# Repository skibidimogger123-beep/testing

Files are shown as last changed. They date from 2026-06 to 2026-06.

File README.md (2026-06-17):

# TDKwarriors — WRO Future Engineers 2026

Welcome to the official repository of **Team TDKwarriors** for **WRO Future Engineers 2026**.

This repository contains the complete engineering documentation, software, CAD files, wiring diagrams, and development history of our autonomous robot vehicle.

---

# Team

## Members

* **Mussabek Nurtas**
* **Mukhtar Gulsim**

## Team Photo

Team photo

---

# Project Overview

Our robot is a compact autonomous vehicle designed for the **WRO Future Engineers 2026** competition.

The robot is capable of completing both competition tasks:

### Open Challenge

* Complete 3 autonomous laps
* Maintain stable lane following
* Navigate using distance sensors

### Obstacle Challenge

* Detect red and green pillars
* Choose the correct passing side
* Avoid obstacles
* Recover to the driving line
* Complete 3 laps
* Perform autonomous parking

---

# Robot Photos

## Front View

Vehicle front

## Back View

Vehicle back

## Left View

Vehicle left

## Right View

Vehicle right

## Top View

Vehicle top

## Bottom View

Vehicle bottom

---

# Mobility and Mechanical Design

## Chassis and Drive System

The robot uses a LEGO Technic based chassis with rear-wheel drive and front-wheel steering.

For steering, we selected the **SPIKE Medium Motor** because it provides significantly higher positioning accuracy compared to the Powered Up motor.

### Engineering Trade-Off

| Option | Advantage | Disadvantage |
| --- | --- | --- |
| SPIKE Medium Motor | High steering precision | Lower torque |
| Powered Up Motor | Higher torque | Lower positioning accuracy |

Since steering precision is critical for lane following and parking, we prioritized accuracy over power.

---

## Mechanical Evolution

During development, the robot underwent multiple design revisions.

### Version 1

* Original steering mechanism
* Wider chassis
* Standard wheels

### Version 2

After testing, we discovered that the original steering mechanism produced inconsistent turns.

Changes:

* Returned to a parallel steering system
* Removed steering gears to eliminate backlash
* Improved steering zero-position accuracy
* Shifted center of mass toward the rear

### Version 3

Further improvements included:

* Reduced chassis width
* Improved maneuverability
* Installed silicone wheels
* Improved traction on the competition field
* Finalized OpenMV-Arduino-Technic Hub architecture

---

## Mechanical Layout

### Chassis Design

Chassis CAD

### Steering System

Steering system

---

## Testing and Improvements

| Test | Observation | Improvement |
| --- | --- | --- |
| Steering Accuracy Test  | Inconsistent turning behavior | Parallel steering system |
| Traction Test | Wheel slip during turns | Silicone wheels |
| Parking Test | Wide chassis reduced maneuverability | Narrower chassis |
| Sensor Calibration Test | Position drift detected | Wall-based calibration |

---

# Power and Sensor Architecture

## Power Distribution

The robot is powered by two 4V lithium batteries.

Most electronic components operate at 3.3V, therefore we use a buck converter to efficiently regulate the voltage.

Advantages of this solution:

* Improved efficiency
* Reduced power loss
* Compact installation
* Better battery utilization

The converter is mounted below the Arduino on a custom 3D-printed bracket.

---

## Power Architecture Diagram

Power architecture

---

## Wiring Diagram

Wiring Diagram

---

# Sensor Placement

The robot uses:

* OpenMV Camera
* Left Distance Sensor
* Front Distance Sensor
* Right Distance Sensor

Sensor placement

---

## Sensor Placement Trade-Off

The side and front sensors are mounted at 90-degree angles.

### Advantages

#### Simpler Mathematics

Sensor readings directly correspond to wall distance.

No projection calculations are required.

#### Direction Detection

The robot can determine driving direction based on which wall disappears first from the sensor field of view.

### Disadvantages

This arrangement creates blind spots around 45 degrees.

We accepted this compromise because it greatly simplifies navigation calculations.

---

# Calibration Method

After extensive testing, we determined that wall-based calibration provides the most reliable performance.

The robot continuously maintains an optimal distance from the inner wall.

---

## Calibration Procedure

1. Place the robot parallel to a wall.
2. Read left and right sensor values.
3. Set target distance.
4. Calculate position error.
5. Apply steering correction.
6. Repeat continuously during operation.

---

## Calibration Flowchart

Calibration Flowchart

---

# Software Architecture

## System Overview

The robot consists of three main processing units:

* OpenMV Camera
* Arduino Mega
* LEGO Technic Hub

---

## Open Challenge Data Flow

1. Distance sensors collect measurements.
2. Arduino processes sensor data.
3. Arduino sends data to the Technic Hub using LumpDeviceBuilder.
4. Technic Hub calculates navigation decisions.
5. Hub sends commands to motors.

---

## Obstacle Challenge Data Flow

1. OpenMV detects colored pillars.
2. OpenMV determines obstacle direction.
3. OpenMV sends command to Arduino.
4. Arduino forwards command to Technic Hub.
5. Technic Hub performs avoidance maneuver.

---

## Software Architecture Diagram

Software Architecture

---

## Open Challenge Flow

Open Challenge flowchart

---

## Obstacle Challenge Flow

Obstacle Challenge flowchart

---

## Software State Machine

The software is organized around the following states:

* INIT
* CALIBRATE
* WAIT_CAMERA
* DRIVE
* DETECT
* AVOID
* RECOVER
* FINISH

State machine

---

# Why We Use Arduino as a Communication Bridge

After multiple experiments, we found that OpenMV communicates more reliably with Arduino than directly with the Technic Hub.

Benefits:

* Better compatibility
* Simpler debugging
* More stable communication
* Easier software integration

The Arduino then transfers information to the Technic Hub through the LumpDeviceBuilder library.

---

# Systems Thinking and Engineering Decisions

## Constraints

During development we faced several engineering constraints:

* Limited available space
* Processing power limitations
* Weight distribution requirements
* Sensor field-of-view restrictions
* Competition time constraints

---

## Design Trade-Offs

### Steering Accuracy vs Motor Power

Benefit:

* Higher steering accuracy

Cost:

* Lower torque

### Sensor Simplicity vs Blind Spots

Benefit:

* Easier calculations

Cost:

* 45° blind zones

### Buck Converter vs Resistors

Benefit:

* Higher efficiency

Cost:

* Slightly more hardware complexity

---

# Bill of Materials (BOM)

| Component | Quantity |
| --- | --- |
| LEGO Technic Hub | 1 |
| SPIKE Medium Motor | 1 |
| Drive Motor | 1 |
| Arduino Mega | 1 |
| OpenMV H7 Plus | 1 |
| Distance Sensors | 3 |
| Buck Converter | 1 |
| Lithium Batteries  | 2 |

---

# Reproducibility

This repository contains all information required to reproduce our robot.

Included:

* Source Code
* CAD Files
* Wiring Diagrams
* Software Documentation
* Calibration Method
* Build Instructions

---

# Build Instructions

## Step 1

Assemble the chassis according to the CAD files.

## Step 2

Install steering and drive motors.

## Step 3

Mount all sensors.

## Step 4

Install Arduino and OpenMV.

## Step 5

Connect all electronics according to the wiring diagram.

## Step 6

Upload software to OpenMV, Arduino and Technic Hub.

## Step 7

Perform calibration.

## Step 8

Run validation tests.

---

# Repository Structure

```text
/
├── assets/
│   ├── images/
│   └── Wire.jpeg
│
├── CAD/
│   ├── chassis
│   ├── sensor_mount
│   └── electronics_mount
│
├── Code/
│   ├── Arduino/
│   ├── OpenMV/
│   └── TechnicHub/
│
├── Documentation/
│
└── README.md
```

---

# Current Repository Status

The repository currently contains:

* Robot photos
* Team photo
* Sensor placement
* Wiring diagram
* Flowcharts
* State machine
* Engineering documentation

Future updates may include:

* Additional test results
* Performance metrics
* New robot revisions

---

# Goal of This Repository

The purpose of this repository is to document the complete development process of our WRO Future Engineers 2026 robot, provide reproducible engineering documentation, and demonstrate the evolution of our design from concept to competition-ready autonomous vehicle.

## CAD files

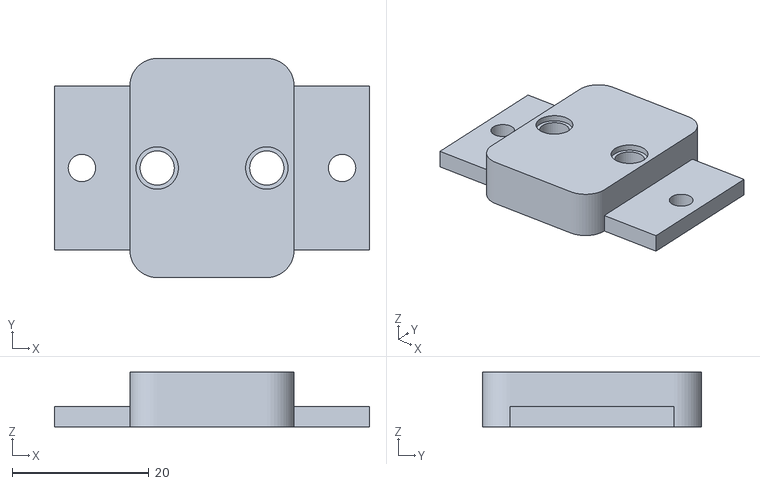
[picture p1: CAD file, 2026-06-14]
CAD/sensorholderfinal.stl
46.0 x 32.0 x 8.00
